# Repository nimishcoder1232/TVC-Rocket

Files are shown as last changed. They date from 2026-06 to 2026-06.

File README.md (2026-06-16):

# TVC-Rocket
This is the repo for my TVC rocket that took two years to develop. 

This is the last revision that actually worked. At the end of my 8th-grade year, there were many other iterations, but I have lost the documentation for those. 

Thumbnail/screenshot: 


PCB: 



The goal of this was to make a thrust vector controlled rocket that can stabilize itself on the way up. This goal ended up being completely successful. 
Demo: 
https://drive.google.com/file/d/10EWHrPkHGs0dUHyr1Sujefc27muy-WCw/view?usp=sharing

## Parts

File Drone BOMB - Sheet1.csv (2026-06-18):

Item Name | Qty | Price (total) (USD) | Item link | Notes
Brushless motors and ESC | 1 | $53.00 | https://www.amazon.com/gp/product/B0BW5H7Y8Q/ref | This is an example part! Add things to note here.
Batteries | 1 | $53.00 | https://www.amazon.com/gp/product/B09CTSD386/ref
Cost to hackclub | 106$ | (Dont forget tax :D)
Stuff I will provide myself:
GNSS GPS | 1 |  | https://www.amazon.com/hiBCTR-GY-NEO6MV2-Controller-Ceramic-Antenna/dp/B0FWC1J7J4/ref
Fillament | 1 |  | (Varrious Sources)
ESP 32 s3 | 1 |  | https://www.amazon.com/Development-ESP32-S3-DevKit-Bluetooth-Internet-ESP32-S3-1-N16R8/dp/B0GVQJ5TST/ref
BMI270 | 1 |  | https://www.sparkfun.com/sparkfun-6dof-imu-breakout-bmi270-qwiic.html
LM317 | 1 |  | https://www.amazon.com/ALLECIN-LM317T-Voltage-Regulator-Adjustable/dp/B0CBLN2X7H/ref
Resistors | 1 |  | https://www.amazon.com/ONJYHK-100Values-Resistor-Resistors-Assortment/dp/B0GJYDKNPC/ref=
Capasitors | 1 |  | https://www.amazon.com/ALLECIN-Electrolytic-Capacitor-Assortment-Kit/dp/B0C1VBXCQM/ref

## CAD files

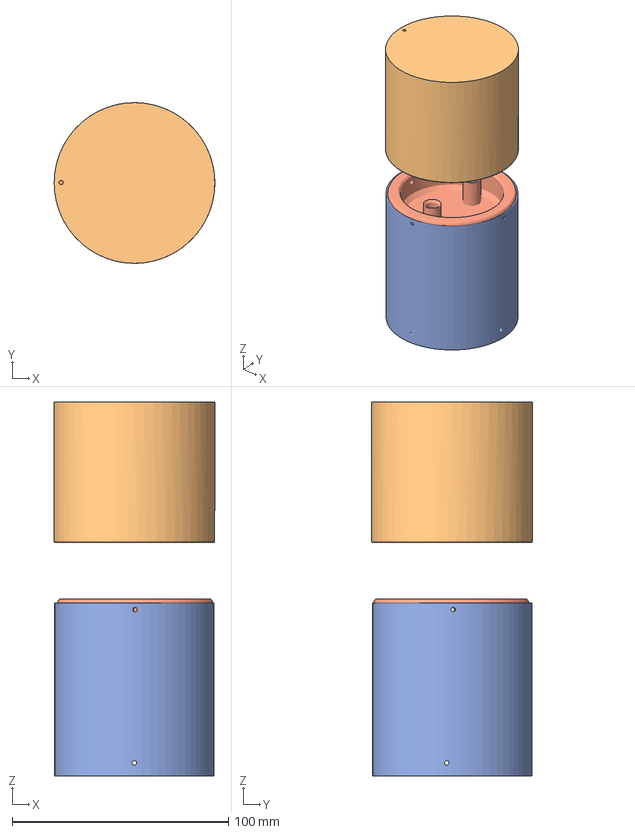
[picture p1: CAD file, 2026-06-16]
CAD/Coupler Section.step
74.4 x 74.4 x 173.1 mm

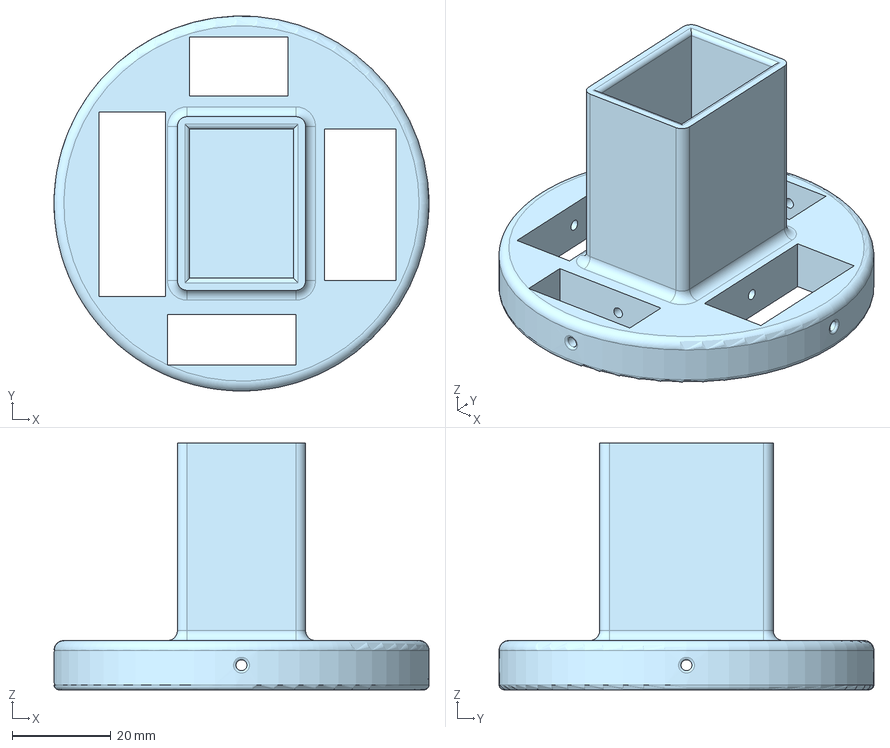
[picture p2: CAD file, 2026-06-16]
CAD/Battery mount.step
76.0 x 76.0 x 50.0 mm

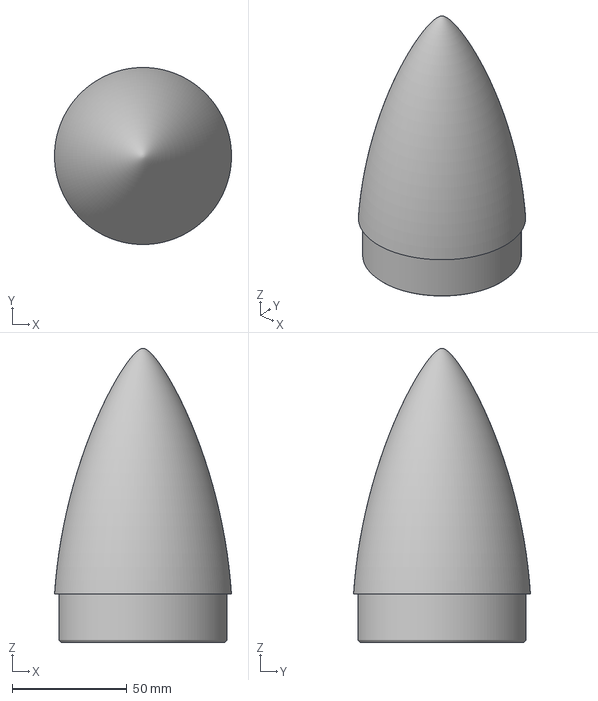
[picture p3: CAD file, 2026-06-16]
CAD/Nosecone.step
77.0 x 77.0 x 127.9 mm

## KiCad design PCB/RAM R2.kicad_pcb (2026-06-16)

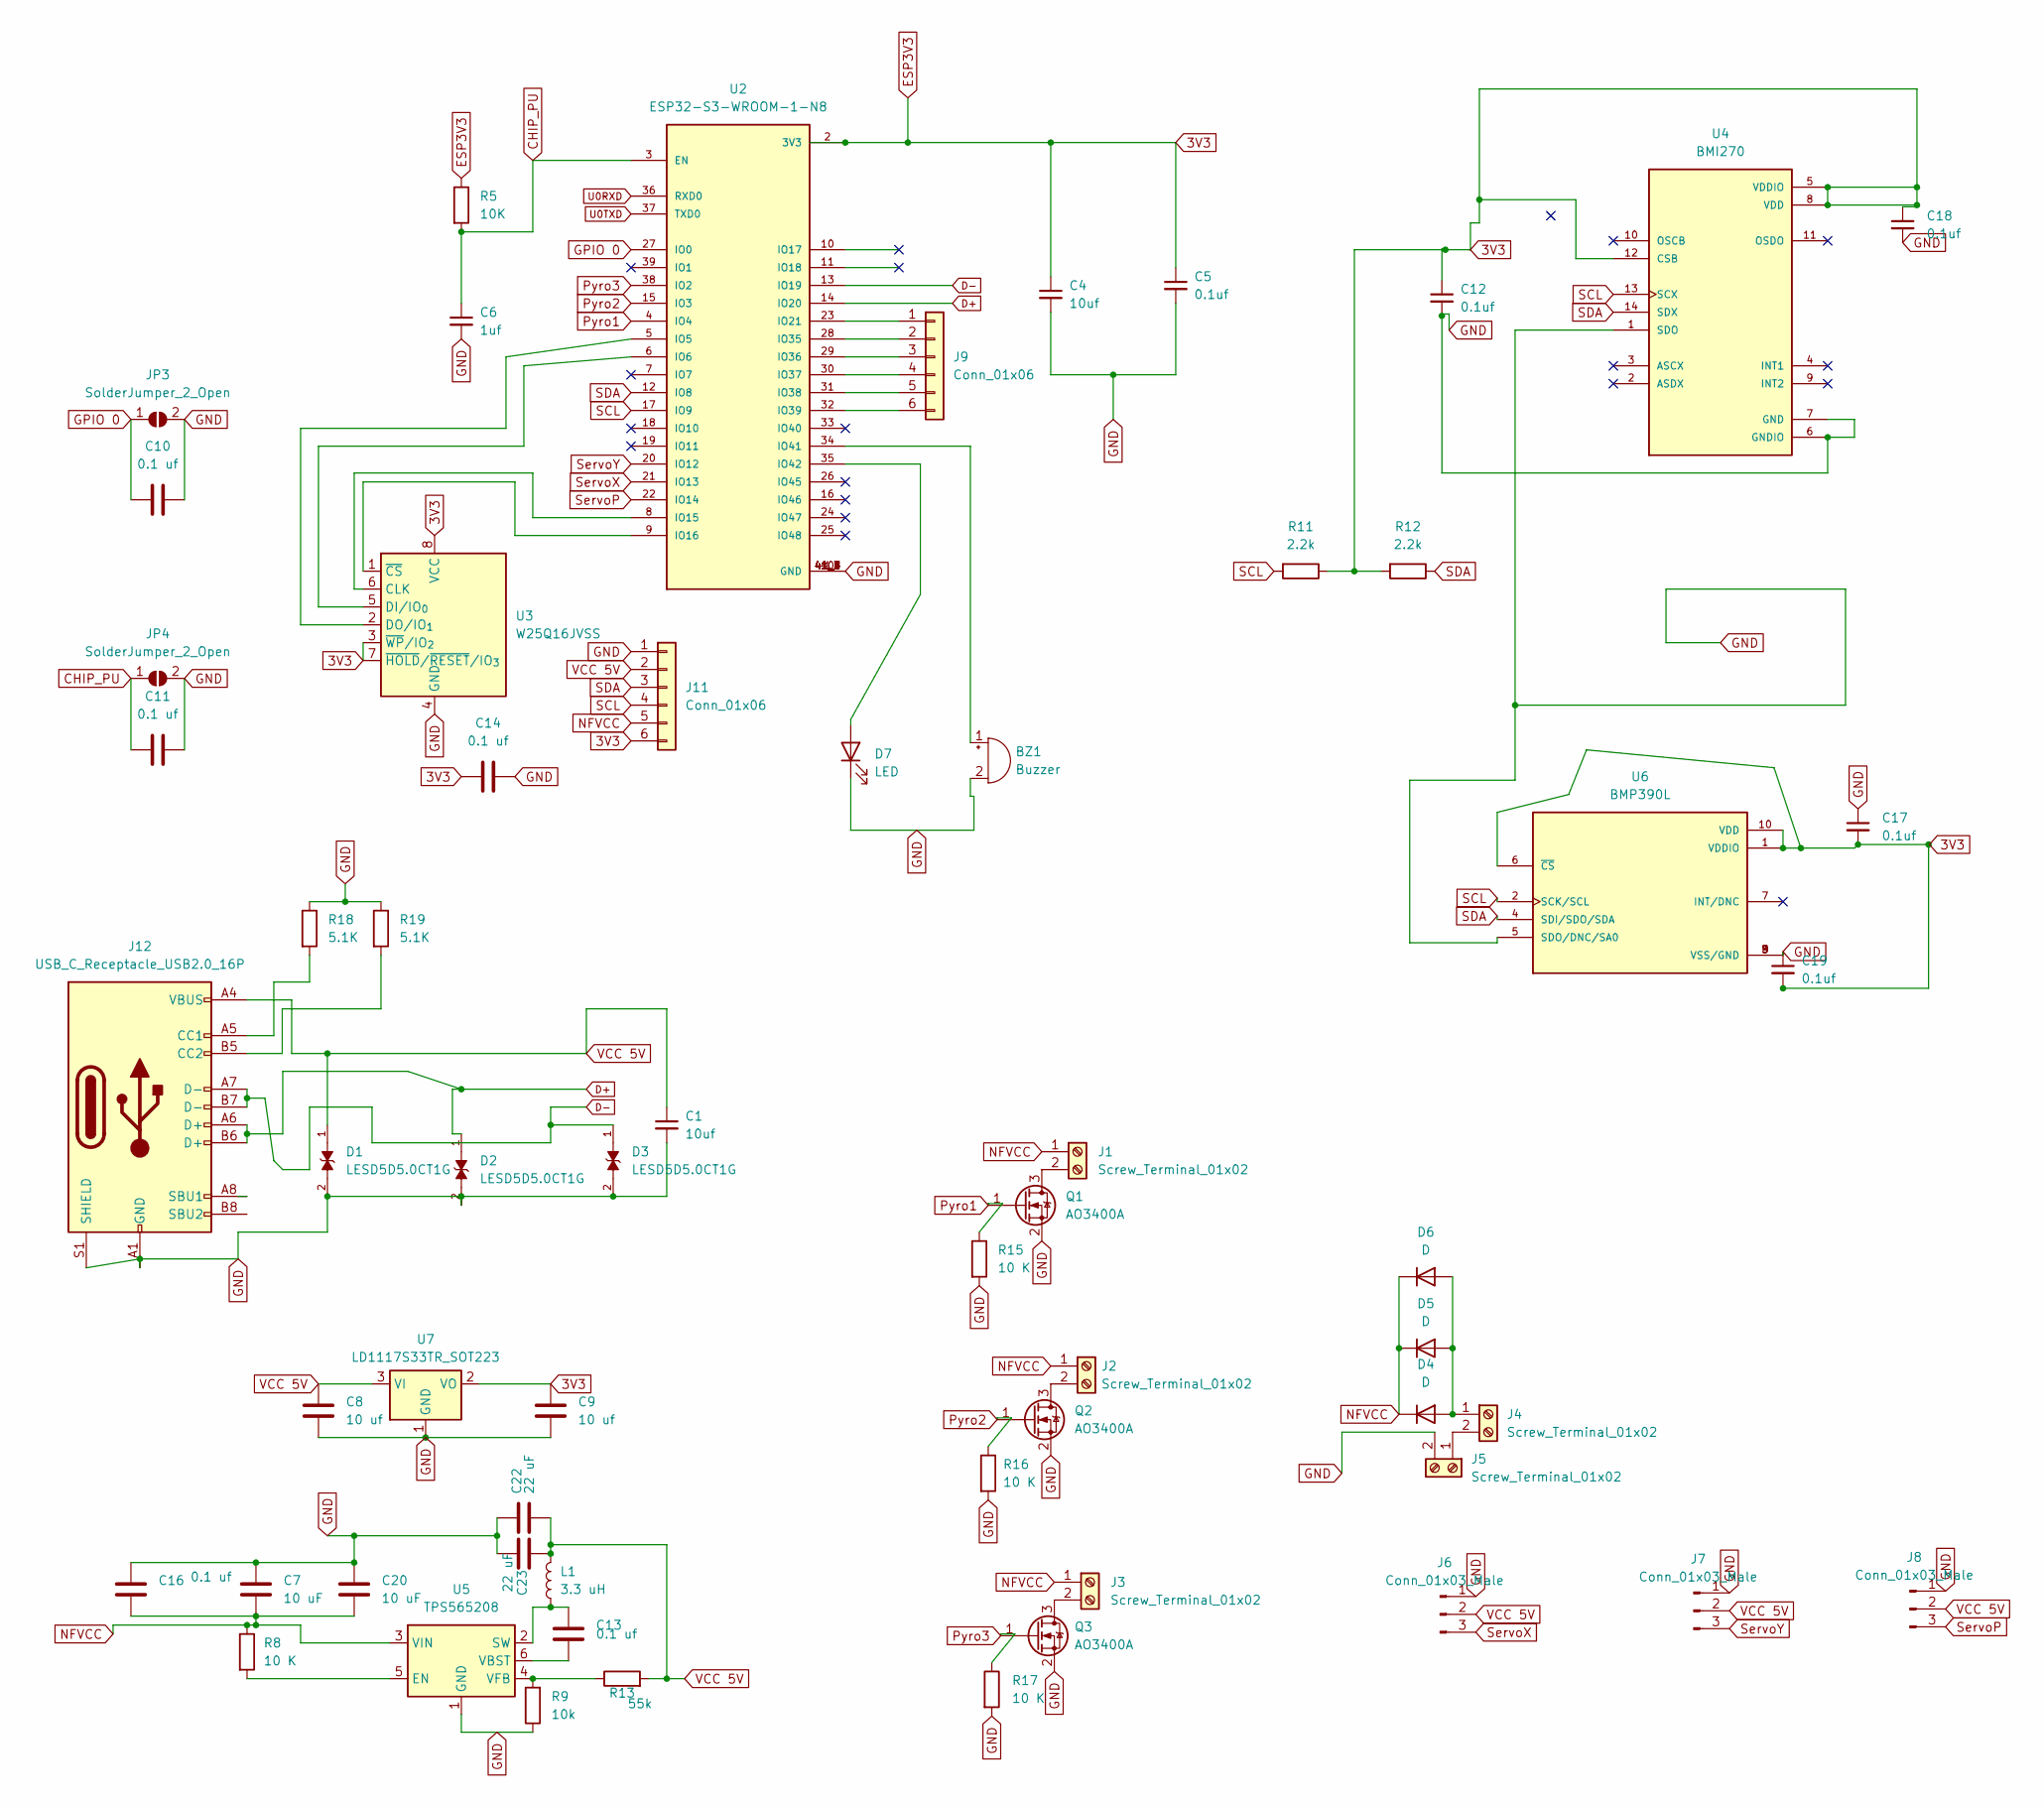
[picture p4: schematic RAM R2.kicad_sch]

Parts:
BZ1: Buzzer; Buzzer_TDK_PS1240P02BT_D12.2mm_H6.5mm
C1, C4: 10uf; C_0805_2012Metric
C5, C12, C17, C18, C19: 0.1uf; C_0805_2012Metric
C6: 1uf; C_0805_2012Metric
C7, C20: 10 uF; C_0805_2012Metric
C8, C9: 10 uf; C_0805_2012Metric
C10, C11, C13, C14, C16: 0.1 uf; C_0805_2012Metric
C22, C23: 22 uF; C_0805_2012Metric
D1, D2, D3: LESD5D5.0CT1G; TVS_LESD5D5.0CT1G; PARTREV O
D4, D5, D6: D; D_SMA
D7: LED; LED_0805_2012Metric
J1, J2, J3, J4, J5: Screw_Terminal_01x02; TerminalBlock_4Ucon_1x02_P3.50mm_Horizontal
J6, J7, J8: Conn_01x03_Male; PinHeader_1x03_P2.54mm_Vertical
J9, J11: Conn_01x06; 6pad genaric
J12: USB_C_Receptacle_USB2.0_16P; USB_C_Receptacle_GCT_USB4105-xx-A_16P_TopMnt_Horizontal
JP3, JP4: SolderJumper_2_Open; SW_PUSH_6mm_H5mm
L1: 3.3 uH; L_0805_2012Metric
Q1, Q2, Q3: AO3400A; SOT-23
R5: 10K; R_0805_2012Metric
R8, R15, R16, R17: 10 K; R_0805_2012Metric
R9: 10k; R_0805_2012Metric
R11, R12: 2.2k; R_0805_2012Metric
R13: 55k; R_0805_2012Metric
R18, R19: 5.1K; R_0805_2012Metric
U2: ESP32-S3-WROOM-1-N8; XCVR_ESP32-S3-WROOM-1-N8
U3: W25Q16JVSS; SOIC-8_5.3x5.3mm_P1.27mm
U4: BMI270; XDCR_BMI270
U5: TPS565208; SOT-23-6
U6: BMP390L; XDCR_BMP390L; PARTREV 1.7
U7: LD1117S33TR_SOT223; SOT-223-3_TabPin2

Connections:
3V3: C4.1, C5.1, C9.1, C12.1, C14.2, C17.2, C18.1, C19.2, J11.6, R5.1, R11.1, R12.2, U2.2 (3V3), U3.3 (~WP/IO_{2}), U3.7 (~HOLD/~RESET/IO_{3}), U3.8 (VCC), U4.5 (VDDIO), U4.8 (VDD), U4.12 (CSB), U6.1 (VDDIO), U6.6 (~CS), U6.10 (VDD), U7.2 (VO)
CHIP_PU: C6.1, C11.2, JP4.1 (A), R5.2, U2.3 (EN)
D+: D2.1, J12.A6 (D+), J12.B6 (D+), U2.14 (IO20)
D-: D3.1, J12.A7 (D-), J12.B7 (D-), U2.13 (IO19)
GND: BZ1.2 (+), C1.2, C4.2, C5.2, C6.2, C7.1, C8.2, C9.2, C10.1, C11.1, C12.2, C14.1, C16.1, C17.1, C18.2, C19.1, C20.1, C22.1, C23.1, D1.2, D2.2, D3.2, D7.1 (K), J5.2, J6.1, J7.1, J8.1, J11.1, J12.A1 (GND), J12.A12 (GND), J12.B1 (GND), J12.B12 (GND), J12.S1 (SHIELD), JP3.2 (B), JP4.2 (B), Q1.2 (S), Q2.2 (S), Q3.2 (S), R9.1, R15.2, R16.2, R17.2, R18.1, R19.1, U2.1 (GND), U2.40 (GND), U2.41_1 (GND), U2.41_2 (GND), U2.41_3 (GND), U2.41_4 (GND), U2.41_5 (GND), U2.41_6 (GND), U2.41_7 (GND), U2.41_8 (GND), U2.41_9 (GND), U3.4 (GND), U4.1 (SDO), U4.6 (GNDIO), U4.7 (GND), U5.1 (GND), U6.3 (VSS/GND), U6.5 (SDO/DNC/SA0), U6.8 (VSS/GND), U6.9 (VSS/GND), U7.1 (GND)
GPIO 0: C10.2, JP3.1 (A), U2.27 (IO0)
NFVCC: C7.2, C16.2, C20.2, D4.1 (K), D5.1 (K), D6.1 (K), J1.1, J2.1, J3.1, J11.5, R8.1, U5.3 (VIN)
unnamed: BZ1.1 (-), U2.34 (IO41)
unnamed: D4.2 (A), D5.2 (A), D6.2 (A), J4.1
unnamed: D7.2 (A), U2.35 (IO42)
unnamed: J1.2, Q1.3 (D)
unnamed: J2.2, Q2.3 (D)
unnamed: J3.2, Q3.3 (D)
unnamed: J4.2, J5.1
unnamed: J9.1, U2.23 (IO21)
unnamed: J9.2, U2.28 (IO35)
unnamed: J9.3, U2.29 (IO36)
unnamed: J9.4, U2.30 (IO37)
unnamed: J9.5, U2.31 (IO38)
unnamed: J9.6, U2.32 (IO39)
unnamed: J12.A5 (CC1), R18.2
unnamed: J12.B5 (CC2), R19.2
unnamed: U2.5 (IO5), U3.2 (DO/IO_{1})
unnamed: U2.6 (IO6), U3.5 (DI/IO_{0})
unnamed: U2.8 (IO15), U3.6 (CLK)
unnamed: U2.9 (IO16), U3.1 (~CS)
unnamed: R8.2, U5.5 (EN)
unnamed: C13.1, L1.1, U5.2 (SW)
unnamed: C13.2, U5.6 (VBST)
unnamed: R9.2, R13.1, U5.4 (VFB)
Pyro1: Q1.1 (G), R15.1, U2.4 (IO4)
Pyro2: Q2.1 (G), R16.1, U2.15 (IO3)
Pyro3: Q3.1 (G), R17.1, U2.38 (IO2)
SCL: J11.4, R11.2, U2.17 (IO9), U4.13 (SCX), U6.2 (SCK/SCL)
SDA: J11.3, R12.1, U2.12 (IO8), U4.14 (SDX), U6.4 (SDI/SDO/SDA)
ServoP: J8.3, U2.22 (IO14)
ServoX: J6.3, U2.21 (IO13)
ServoY: J7.3, U2.20 (IO12)
U0RXD: U2.36 (RXD0)
U0TXD: U2.37 (TXD0)
VCC 5V: C1.1, C8.1, C22.2, C23.2, D1.1, J6.2, J7.2, J8.2, J11.2, J12.A4 (VBUS), J12.A9 (VBUS), J12.B4 (VBUS), J12.B9 (VBUS), L1.2, R13.2, U7.3 (VI)

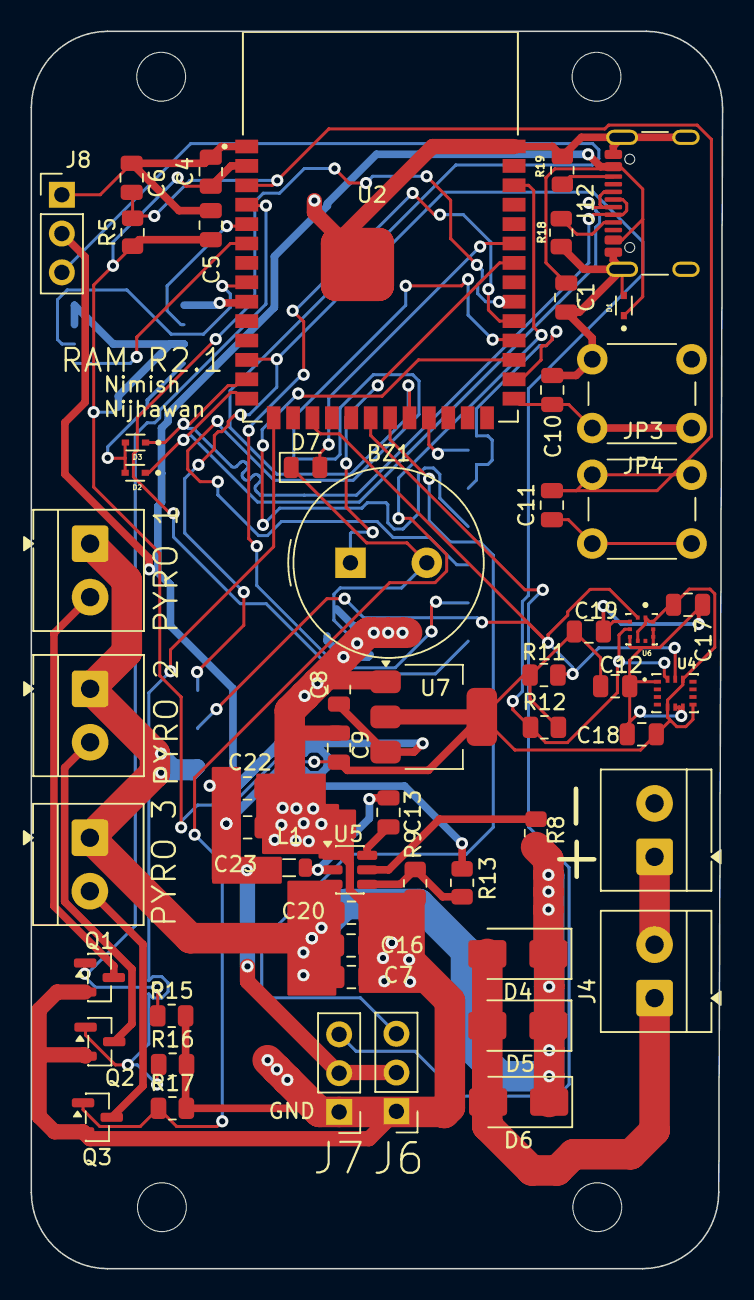
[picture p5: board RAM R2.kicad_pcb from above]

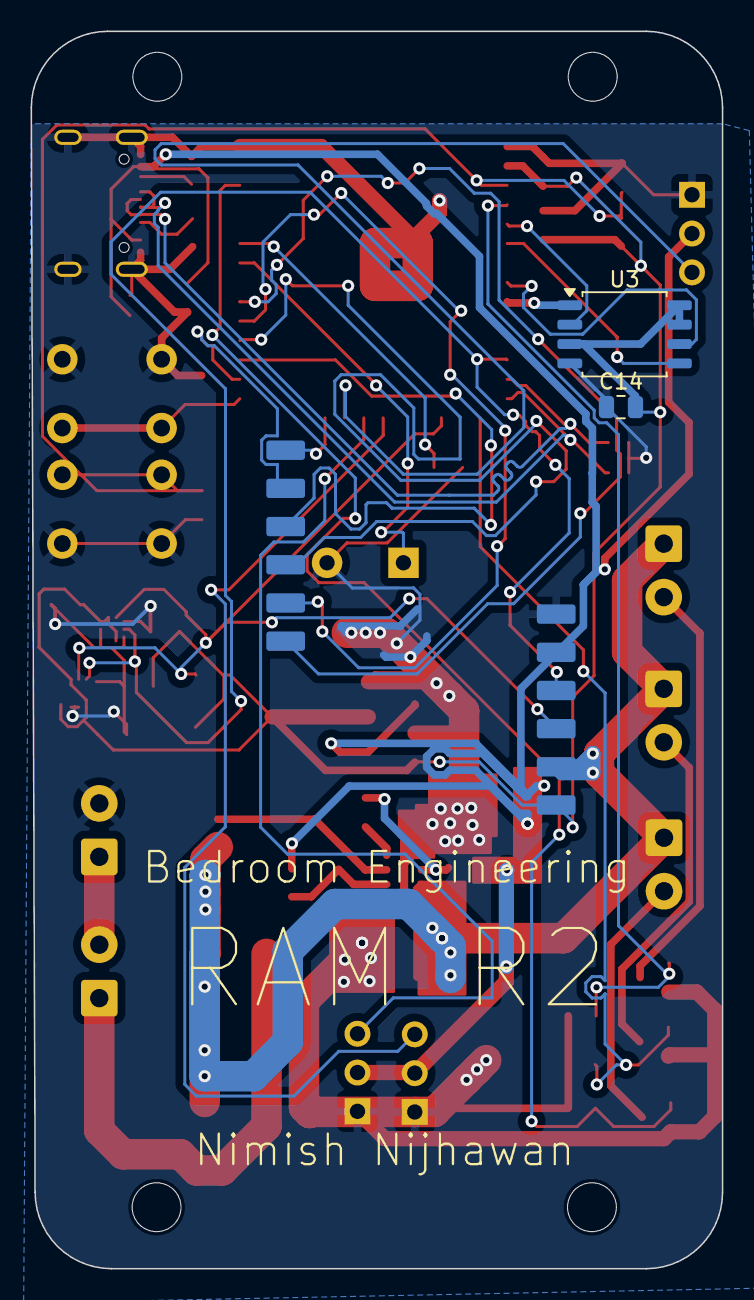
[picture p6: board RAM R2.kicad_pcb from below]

Board: 2 copper layers, 45.2 x 81.0 mm, 61 parts (4 on the bottom side), 39 nets.

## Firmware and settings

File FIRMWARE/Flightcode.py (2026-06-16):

from machine import Pin, PWM
from utime import sleep
import math
import machine
import utime as time
import MPU6050
from bmp280 import *
def quat_to_angle_axis(w, x, y, z):
    angle = 2 * math.acos(w)
    sin_half_angle = math.sqrt(1 - w * w)

    if sin_half_angle < 1e-6:
        # No rotation or invalid, return zero vector
        return (0.0, 0.0, 0.0)

    # Normalize axis and scale by angle
    axis_x = x / sin_half_angle
    axis_y = y / sin_half_angle
    axis_z = z / sin_half_angle

    # Final angle-axis vector (axis * angle)
    return (axis_x * angle, axis_y * angle, axis_z * angle)
# Servo setup
servoy = PWM(Pin(15))
servoy.freq(50)
servox = PWM(Pin(10))
servox.freq(50)
def set_servo_x(cmmd,servo):
    if cmmd > 5 :
        cmmd = 5
    if cmmd < -5:
        cmmd = -5
    cmmd = cmmd * 16 * -1
    angle = cmmd +90
    angle = angle + 12
    angle = angle 
    pulse_width = 1000 + (angle / 180) * 1000
    duty_cycle = int(pulse_width * (65535 / 20000))
    servo.duty_u16(duty_cycle)

def set_servo_y(cmmd,servo):
    if cmmd > 5 :
        cmmd = 5
    if cmmd < -5:
        cmmd = -5
    cmmd = cmmd * 7.4
    angle = cmmd + 90
    angle = angle +5
    angle = angle *1.5
    pulse_width = 1000 + (angle / 180) * 1000
    duty_cycle = int(pulse_width * (65535 / 20000))
    servo.duty_u16(duty_cycle)

set_servo_y(0,servoy)
set_servo_x(0,servox)
# Pyro output
pyro = Pin(12, Pin.OUT)
led = Pin(13, Pin.OUT)
buzzer = Pin(2, Pin.OUT)
# I2C setup for BMP280
sdaPIN = machine.Pin(0)
sclPIN = machine.Pin(1)
bus = machine.I2C(0, sda=sdaPIN, scl=sclPIN, freq=400000)
time.sleep(0.1)
led.on()
buzzer.off()
time.sleep(10)
buzzer.on()
# BMP280 setup
bmp = BMP280(bus)
bmp.use_case(BMP280_CASE_INDOOR)
sea_level_pressure = 100820


# Datalogger setup
led.off()
logfile = open("datalog.txt", "w")
logfile.write("time_ms   xpos    ypos  roll zaccel  xout    yout    altitude \n")

def set_servo_x(cmmd,servo):
    if cmmd > 5 :
        cmmd = 5
    if cmmd < -5:
        cmmd = -5
    cmmd = cmmd * 16 * -1
    angle = cmmd +90
    angle = angle + 12
    angle = angle 
    pulse_width = 1000 + (angle / 180) * 1000
    duty_cycle = int(pulse_width * (65535 / 20000))
    servo.duty_u16(duty_cycle)

def set_servo_y(cmmd,servo):
    if cmmd > 5 :
        cmmd = 5
    if cmmd < -5:
        cmmd = -5
    cmmd = cmmd * 7.4
    angle = cmmd + 90
    angle = angle +5
    angle = angle *1.5
    pulse_width = 1000 + (angle / 180) * 1000
    duty_cycle = int(pulse_width * (65535 / 20000))
    servo.duty_u16(duty_cycle)

set_servo_y(0,servoy)
set_servo_x(0,servox)

def to_euler_angles(w, x, y, z):
    sinr_cosp = 2 * (w * x + y * z)
    cosr_cosp = 1 - 2 * (x * x + y * y)
    roll = math.atan2(sinr_cosp, cosr_cosp)

    sinp = math.sqrt(1 + 2 * (w * y - x * z))
    cosp = math.sqrt(1 - 2 * (w * y - x * z))
    pitch = 2 * math.atan2(sinp, cosp) - math.pi / 2

    siny_cosp = 2 * (w * z + x * y)
    cosy_cosp = 1 - 2 * (y * y + z * z)
    yaw = math.atan2(siny_cosp, cosy_cosp)

    return roll, pitch, yaw

class Quaternion:
    def __init__(self, w, x, y, z):
        self.w, self.x, self.y, self.z = w, x, y, z

    def __mul__(self, other):
        w1, x1, y1, z1 = self.w, self.x, self.y, self.z
        w2, x2, y2, z2 = other.w, other.x, other.y, other.z
        return Quaternion(
            w1*w2 - x1*x2 - y1*y2 - z1*z2,
            w1*x2 + x1*w2 + y1*z2 - z1*y2,
            w1*y2 - x1*z2 + y1*w2 + z1*x2,
            w1*z2 + x1*y2 - y1*x2 + z1*w2
        )

    def normalize(self):
        mag = math.sqrt(self.w**2 + self.x**2 + self.y**2 + self.z**2)
        self.w /= mag
        self.x /= mag
        self.y /= mag
        self.z /= mag

# MPU6050 setup
i2c = machine.I2C(0, sda=machine.Pin(0), scl=machine.Pin(1))
mpu = MPU6050.MPU6050(i2c)

# Calibration
print("Calibration")
mpu.wake()
time.sleep(3)
xoff = yoff = zoff = 0

time.sleep(1)
for _ in range(5000):
    x, y, z = mpu.read_gyro_data()
    xoff += x
    yoff += y
    zoff += z
xoff /= 5000
yoff /= 5000
zoff /= 5000
print(f"x{xoff} y{yoff} z{zoff}")

#xoff = -0.0008994192
#yoff = 0.000619975
#zoff = 0.0005649991



led.on()
baseline_altitude = 44330 * (1 - (bmp.pressure / sea_level_pressure) ** 0.1903)
buzzer.off()
def detect_launch():
    threshold = -1.5
    print("Waiting for launch...")
    while True:
        time.sleep(0.01)
        x, y, z = mpu.read_accel_data()
        print(f"Accel (g): x={x:.2f}, y={y:.2f}, z={z:.2f}")
        if x < threshold:
            print("Launch detected!")
            return

detect_launch()
wholetime = time.ticks_ms()

# PID and quaternion initialization
xpos = ypos = 0
p, i, d = 0.4, 0.2, 0.13
xp = xi = xd = yp = yi = yd = 0
prevx = prevy = 0
cycletime = time.ticks_ms()
time.sleep(0.01)
start_time = time.ticks_ms()
statequat = Quaternion(1, 0, 0, 0)

# Control loop
while time.ticks_ms() - start_time < 2800:
    elapsed = (time.ticks_ms() - cycletime) / 1000
    cycletime = time.ticks_ms()
    s = elapsed
    acelx, acely, acelz = mpu.read_accel_data()
    x, y, z = mpu.read_gyro_data()
    x -= xoff
    y -= yoff
    z -= zoff

    xpos += x * elapsed
    ypos += y * elapsed
    zpos = z * elapsed

    xr = math.radians(x * elapsed)
    yr = math.radians(y * elapsed)
    zr = math.radians(z * elapsed)
    detasq = xr**2 + yr**2 + zr**2
    deta = math.sqrt(detasq)
    if deta != 0:
        ux, uy, uz = xr/deta, yr/deta, zr/deta
    else:
        ux = uy = uz = 0

    w = math.cos(deta/2)
    s = math.sin(deta/2)
    rotationquat = Quaternion(w, s*ux, s*uy, s*uz)
    statequat = statequat * rotationquat
    statequat.normalize()

    xq, yq, roll = quat_to_angle_axis(statequat.w,statequat.x,statequat.y,statequat.z)
    xpos = math.degrees(roll)
    roll = math.degrees(xq)
    ypos = math.degrees(yq)
    print(f"x{xpos}  y{ypos}")
    xp = xpos * p
    xi += xpos * elapsed * i
    xd = ((xpos - prevx) / elapsed) * d
    xout = xp + xi + xd
 
    prevx = xpos
    xout = -1* xout
    set_servo_x(xout, servox)

    yp = ypos * p
    yi += ypos * elapsed * i
    yd = ((ypos - prevy) / elapsed) * d
    yout = yp + yi + yd
    prevy = ypos
    set_servo_y(yout, servoy)

    # Logging
    pressure = bmp.pressure
    altitude = 44330 * (1 - (pressure / sea_level_pressure) ** 0.1903) - baseline_altitude
    temperature = bmp.temperature
    logfile.write(f"{time.ticks_ms() - wholetime }        {xpos:<7.2f} {ypos:<7.2f} {roll} {acelx} {xout:<7.2f} {yout:<7.2f} {altitude}\n")
print(s)
# Apogee detection and logging
highest = altitude
while True:
    pressure = bmp.pressure
    temperature = bmp.temperature
    altitude = 44330 * (1 - (pressure / sea_level_pressure) ** 0.1903) - baseline_altitude
    logfile.write(f"{time.ticks_ms() - wholetime} {'NA':<7} {'NA':<7} {'NA':<7} {'NA':<7} {altitude}\n")

    if altitude > highest:
        highest = altitude
    if altitude < highest - 0.5:
        print("Parachute deployed.")
        break
    time.sleep(0.1)
led.off()
set_servo_y(0, servoy)
set_servo_x(0, servox)
pyro.on()
time.sleep(3)
pyro.off()
logfile.close()
print("Flight complete. Data logged to datalog.txt.")

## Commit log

2026-06-16 Rename Final ROcket.step.zip to CAD/Final ROcket.step.zip
2026-06-16 Rename RAM R2.kicad_sch to PCB/RAM R2.kicad_sch
    [RAM R2.kicad_sch]
2026-06-16 Rename RAM R2.kicad_pcb to PCB/RAM R2.kicad_pcb
    [RAM R2.kicad_pcb]
2026-06-16 Rename RAM R2.kicad_pro to PCB/RAM R2.kicad_pro
2026-06-16 Rename RAM R2.kicad_prl to PCB/RAM R2.kicad_prl
2026-06-16 Expand README with project details and images
    Added additional details about the rocket's development and included images of the PCB.
2026-06-18 Rename Drone BOMB - Sheet1.csv to BOM.csv
    [BOM.csv]
